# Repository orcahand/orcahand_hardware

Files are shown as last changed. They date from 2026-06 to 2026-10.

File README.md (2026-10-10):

<p align="center">
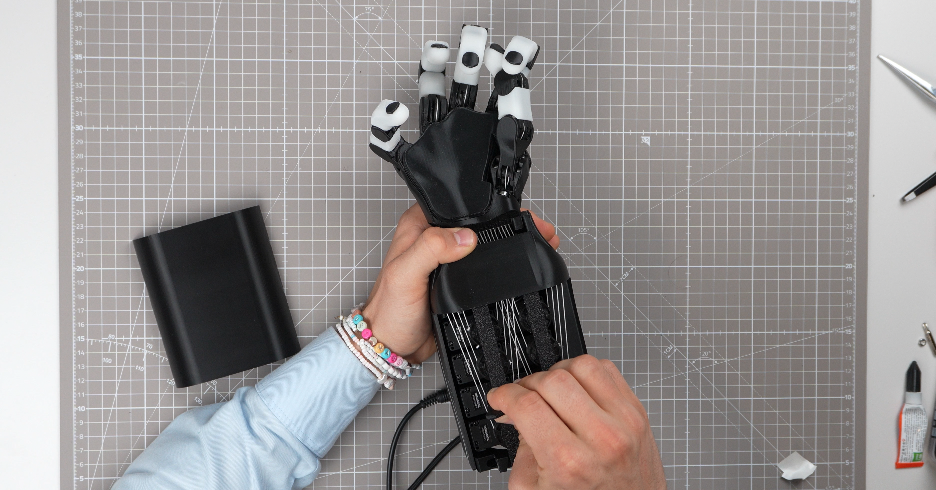
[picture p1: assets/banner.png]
ORCA Hand
  
</p>

<div align="center" style="line-height: 1;">
  
  
  
  
  <br>
  
</div>

# ORCA Hand Files

CAD and print files for the ORCA robotic hand.

## Print Files

There are two hand variants. Each ships one print file for the hand itself and one for the silicone skin molds:

| Variant | Hand print file | Silicone mold file |
|---|---|---|
| **Base hand** | `orca_v2/base/Prints-1100.3mf` | `orca_v2/base/SiliconeMolds-1100.3mf` |
| **Touch hand** (touch sensors in the fingertips) | `orca_v2/touch/Prints-2100.3mf` | `orca_v2/touch/SiliconeMolds-2100.3mf` |

All files are Bambu Lab Studio projects with pre-arranged plates and print settings.

### Hand print files (`Prints-*.3mf`)

Everything you need to print the hand. The ORCA Hand supports both **Feetech** and **Dynamixel** servos: print plate 1 (`DYNAMIXEL`) *or* plate 2 (`FEETECH`) for the tower, depending on your actuators. Every other plate is the same for both.

The print files also include the **skin parts as direct TPU prints** — the finger skins and the carpal skin — on their own `(TPU)` plates. They are white in the base hand and black in the touch hand. Printing the skins in TPU is the quickest way to get a complete hand.

### Silicone mold files (`SiliconeMolds-*.3mf`)

Print these molds, then cast the skins in silicone. **We recommend silicone skins** — they grip better and last longer than TPU. If you want something quick and dirty, the TPU-printed skins from the hand print file work as well.

The mold files contain the finger skin molds with their clips, the carpal molds, and the funnels for pouring. One plate (`WITH TPU (~85A)`) prints the flexible carpal mold halves in soft TPU; everything else is PLA.

> **Note:** It is still unverified whether the TPU-printed carpal skin fits into the carpals as tightly as the silicone one. If it is loose, glue it in.

If you prefer compression molding over pouring, `orca_v2/base/07_Molds/Compression-Molds.3mf` contains the compression molds for the finger and carpal skins.

## Repository Structure

```
orca_v2/                          # Current ORCA hand — shared base + variants
  base/                           # Base hand
    Prints-1100.3mf               # Hand print file (Dynamixel + Feetech plates)
    SiliconeMolds-1100.3mf        # Silicone skin molds
    01_Fingers/*.stl              # STL sources
    02_Carpals/*.stl              #   (incl. *_Skin_TPU.stl carpal skins)
    03_Wrist/*.stl
    04_ForeArm/*.stl
    05_Spools/*.stl
    06_CNC/                       # CNC parts (STEP + drawings)
    07_Molds/*.stl                # Mold STLs
    07_Molds/Compression-Molds.3mf  # Compression molds (alternative to pouring)
    09_Skin/*.stl                 # Finger skin STLs (TPU)
    <section>/step_files/*.step   # STEP sources, named like the STL they belong to
    ASSEMBLY_ADDENDUM.md          # Assembly notes
  touch/                          # Touch-sensor variant
    Prints-2100.3mf               # Hand print file (Dynamixel + Feetech plates)
    SiliconeMolds-2100.3mf        # Silicone skin molds
    01_Fingers/*-Touch.stl        # Override STLs; everything else comes from base/
    02_Carpals/*-Touch.stl
  lite/                           # Lite variant — STL + STEP sources only
  joint-sensing/                  # Joint-sensing variant
    PrintsJointSensing.3mf

orca_v1/                          # V1 design (self-contained, legacy)
  Print_Files_Bambu/*.3mf
  ORCA_Fingers/*.stl
  ...
```

Variant 3MFs under `orca_v2/<variant>/` resolve part names against their own variant folder first, then `orca_v2/base/`, so they pick up shared STLs from base without duplication (a variant's own copy of a name wins over base). Edit a base STL once and every variant 3MF that references it gets updated.

## Updating Print Files After STL Changes

```bash
# Find which 3MF(s) contain a given STL (cascades across variants)
python3 scripts/find_3mf_for_file.py orca_v2/base/05_Spools/BaseSpool.stl

# Update all parts in a 3MF from source STLs (variants pull base parts too)
python3 scripts/update_3mf.py orca_v2/touch/Prints-2100.3mf --all

# Preview without writing
python3 scripts/update_3mf.py orca_v2/base/Prints-1100.3mf --all --dry-run

# List parts inside a 3MF
python3 scripts/update_3mf.py orca_v2/base/Prints-1100.3mf --list

# End-to-end: find changed STLs, update affected 3MFs, commit and push
python3 scripts/update-print-files.py --git
```

## License

Copyright (c) 2026 ORCA Dexterity, Inc.

All files in this repository — hardware designs (CAD/STL/3MF) and source code —
are licensed under the [Creative Commons Attribution 4.0 International License
(CC BY 4.0)](LICENSE). You may share and adapt the material for any purpose,
including commercially, with appropriate credit. No patent or trademark rights
are granted.

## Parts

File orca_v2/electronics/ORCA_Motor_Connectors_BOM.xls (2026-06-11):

Comment | Designator | Footprint | JLCPCB Part #
PM254V-11-03-H85 | H1,H2 | HDR-TH_3P-P2.54-V-F | C541850

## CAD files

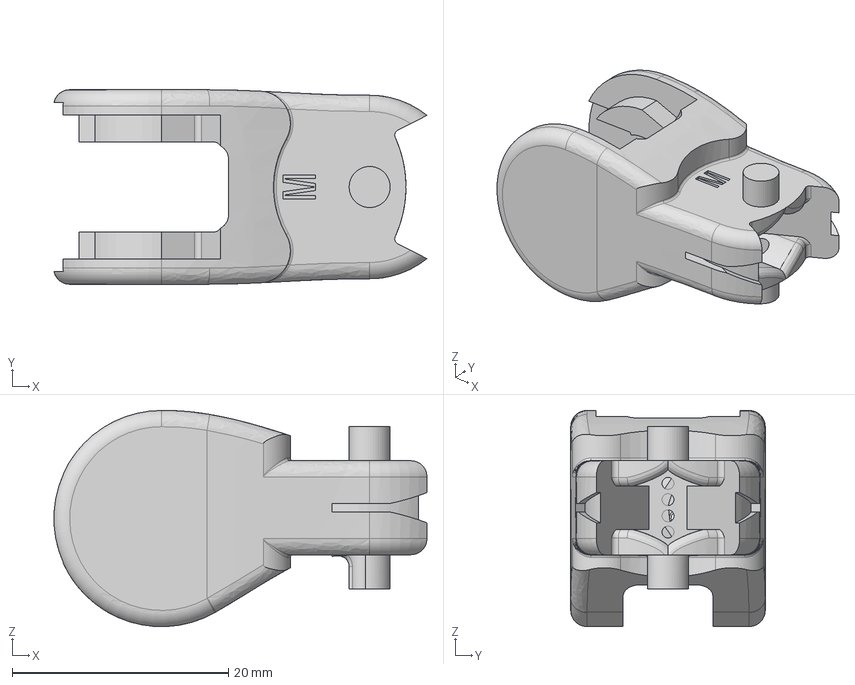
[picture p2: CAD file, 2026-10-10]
orca_v2/base/01_Fingers/step_files/M-AP.step
34.5 x 18.0 x 20.0 mm

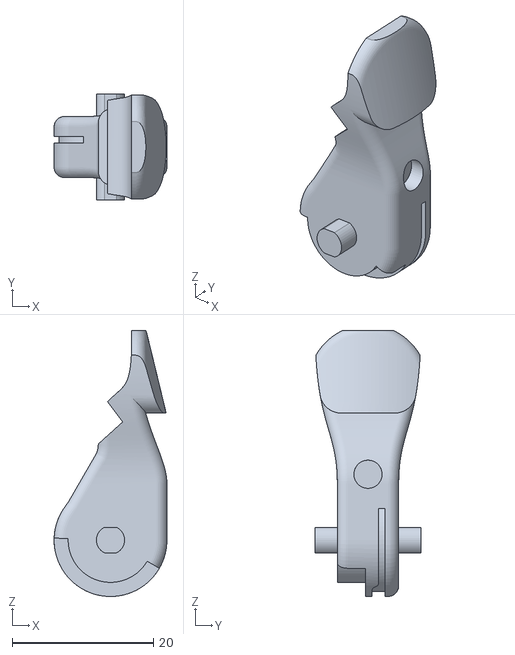
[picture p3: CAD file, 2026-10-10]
orca_v2/base/01_Fingers/T-DP.stl
16.0 x 15.0 x 37.7

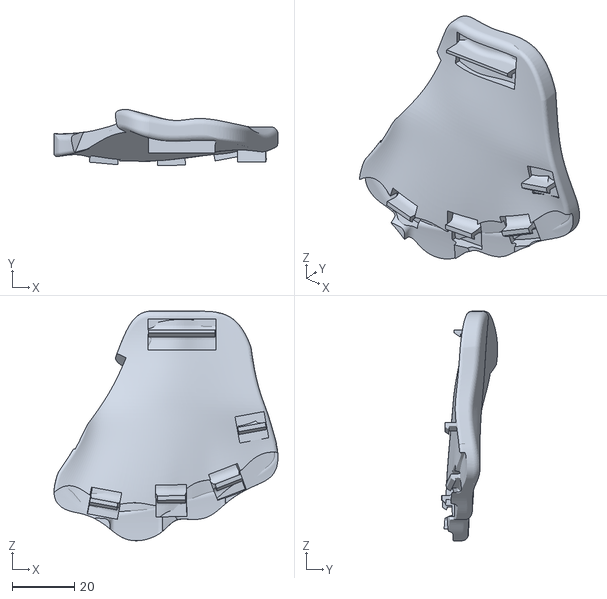
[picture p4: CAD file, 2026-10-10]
orca_v2/base/02_Carpals/L-Carpals_Skin_TPU.stl
72.2 x 18.2 x 74.0

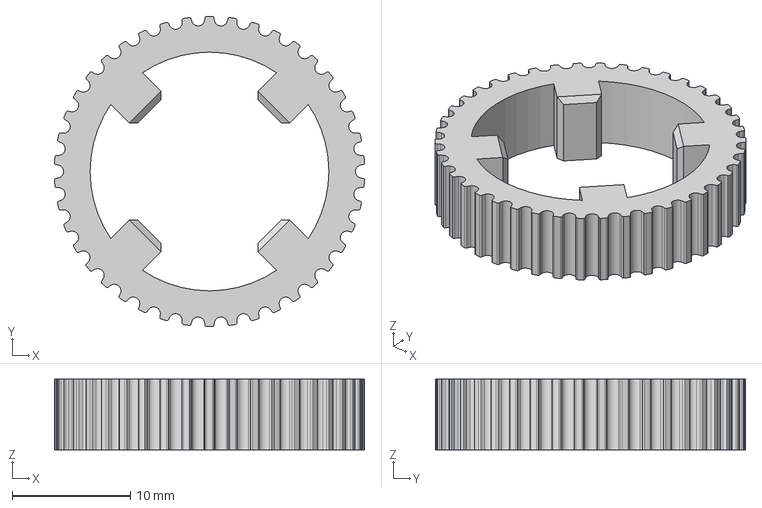
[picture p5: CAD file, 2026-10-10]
orca_v2/base/02_Carpals/step_files/CarpalsTeeth.step
26.2 x 26.3 x 6.00 mm

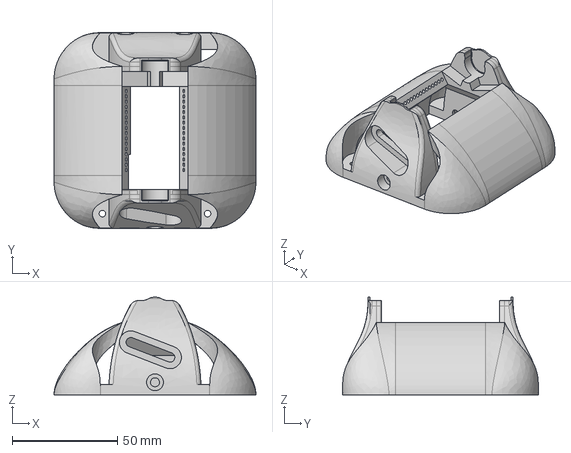
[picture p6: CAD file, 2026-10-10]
orca_v2/base/03_Wrist/step_files/WristStructure_Dynamixel.step
96.0 x 93.0 x 46.5 mm

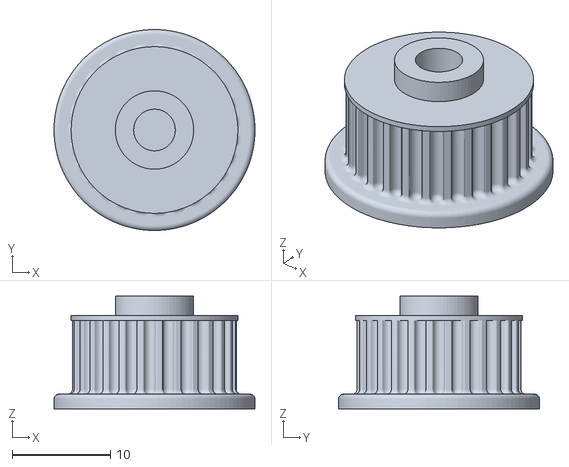
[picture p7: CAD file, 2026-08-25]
orca_v2/base/03_Wrist/WristTeeth.stl
20.5 x 20.5 x 11.5

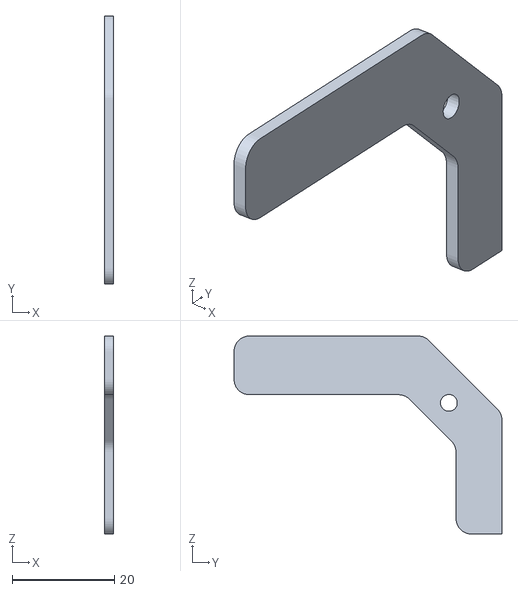
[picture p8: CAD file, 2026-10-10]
orca_v2/base/04_ForeArm/HullBack_CableCover.stl
1.85 x 52.5 x 38.8

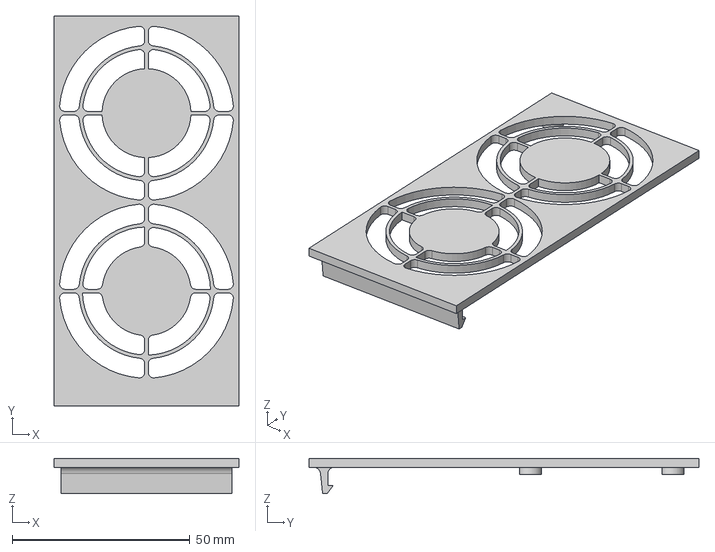
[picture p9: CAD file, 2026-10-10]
orca_v2/base/04_ForeArm/step_files/FanCover_TwoFans.step
52.0 x 109.6 x 9.90 mm

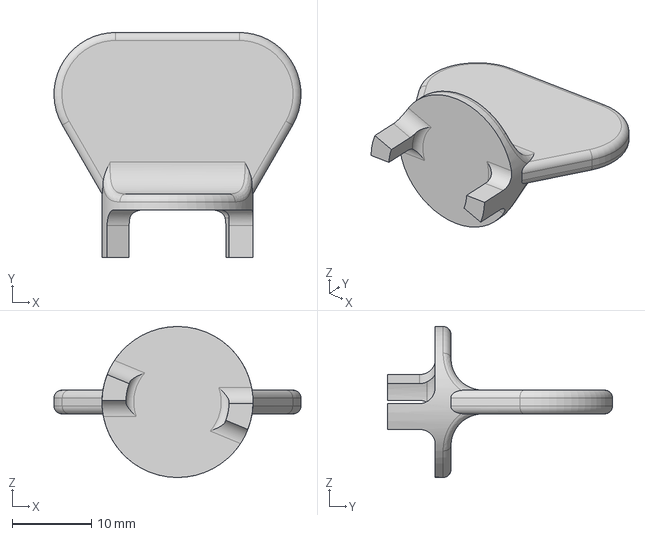
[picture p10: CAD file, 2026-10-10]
orca_v2/base/05_Spools/step_files/SpoolTensioner.step
31.1 x 28.3 x 19.0 mm

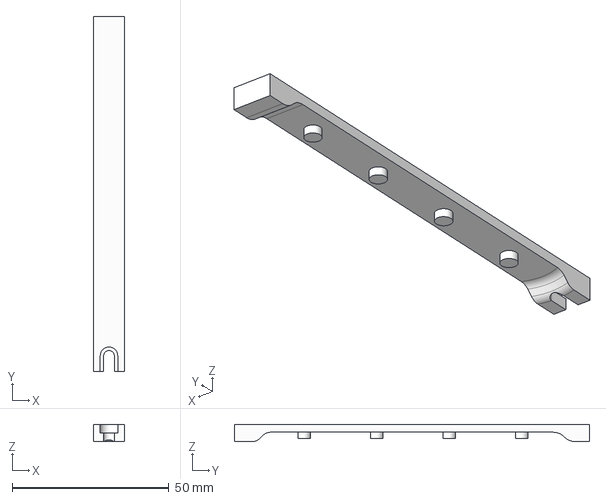
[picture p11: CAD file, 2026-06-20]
orca_v2/base/06_CNC/SpoolHolder_CNC.step
10.0 x 113.3 x 5.50 mm

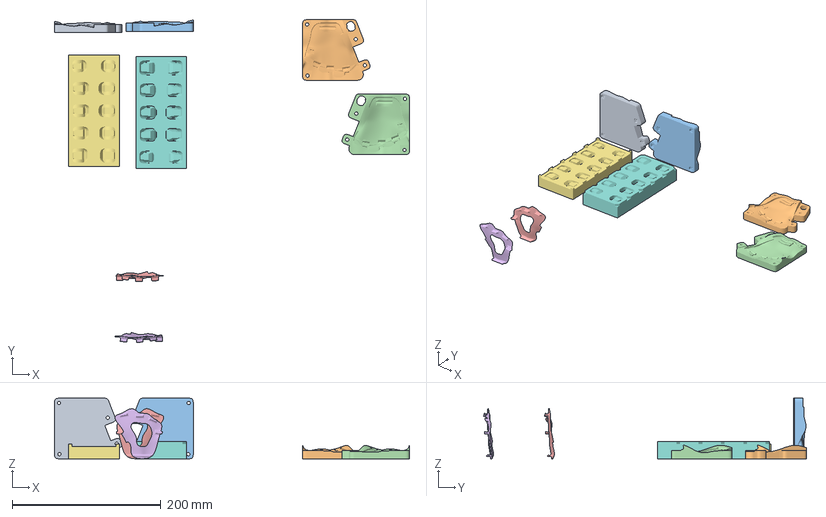
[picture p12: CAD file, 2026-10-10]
orca_v2/base/07_Molds/Compression-Molds.3mf
476.9 x 433.4 x 81.4 mm
L-CarpalsMold-A.stl
L-CarpalsMold-B.stl
R-CarpalsMold-A.stl
R-CarpalsMold-B.stl
CORE-L.stl
CORE-R.stl
PP_Skin_BottomMold.stl
PP_Skin_TopMold.stl

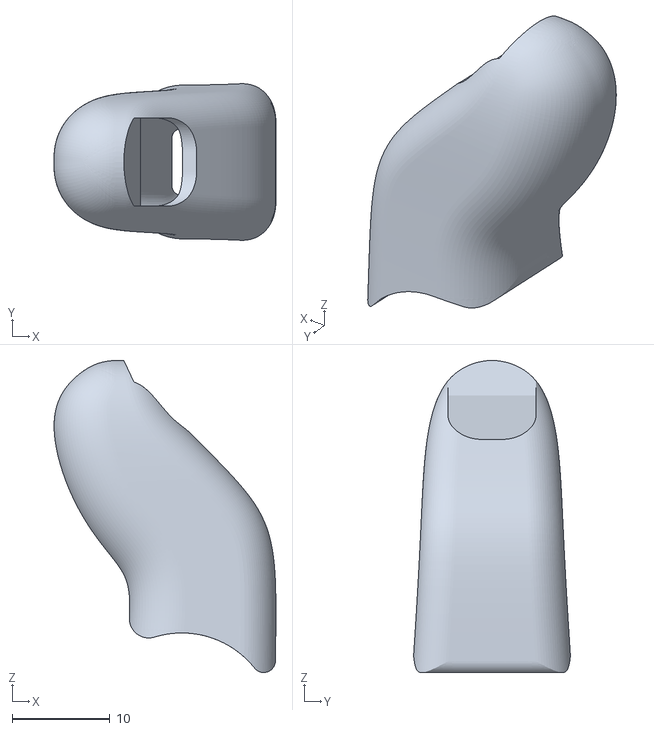
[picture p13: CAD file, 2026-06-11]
orca_v2/base/09_Skin/DP-Skin_P-DP-Skin_Skin.stl
22.7 x 16.0 x 31.9

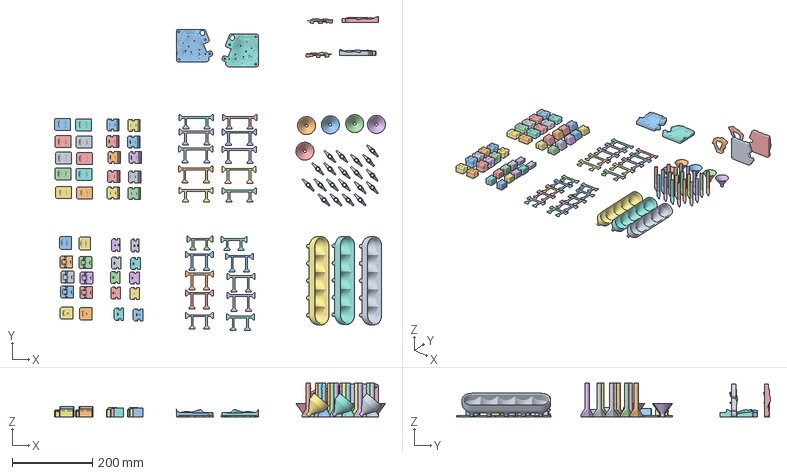
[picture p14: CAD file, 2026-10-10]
orca_v2/base/SiliconeMolds-1100.3mf
826.3 x 783.8 x 84.0 mm
L-CarpalsMold-A-Funnel.stl
Cylinder.stl x 20
L-CarpalsMold-B-Funnel.stl
R-CarpalsMold-A-Funnel.stl
R-CarpalsMold-B-Funnel.stl
CORE-L.stl
DP-SkinMold_M-DP-SkinMold_Clip.stl x 6
CORE-R.stl
DP-SkinMold_P-DP-SkinMold_Clip.stl x 2
PP-SkinMold_T-PP-Skinmold_BottomMold.stl x 2
PP-SkinMold_I-PP-SkinMold_BottomMold.stl x 2
PP-SkinMold_P-PP-SkinMold_BottomMold.stl x 2
M-DP-SkinMold_BottomMold.stl x 6
T-DP-BottomMold.stl x 2
PP-SkinMold_I-PP-SkinMold_TopMold.stl x 2
PP-SkinMold_P-PP-SkinMold_TopMold.stl x 2
DP-SkinMold_M-DP-SkinMold_TopMold.stl x 6
T-DP-Clip.stl x 2
T-DP-TopMold.stl x 2
P-DP-SkinMold_BottomMold.stl x 2
P-DP-SkinMold_TopMold.stl x 2
PP-SkinMold_M-PP-SkinMold_BottomMold.stl x 4
PP-SkinMold_M-PP-SkinMold_TopMold.stl x 4
PP-SkinMold_T-PP-Skinmold_TopMold.stl x 2
PP-SkinMold_I-PP-SkinMold_Clip.stl x 2
PP-SkinMold_P-PP-SkinMold_Clip.stl x 2
PP-SkinMold_T-PP-Skinmold_Clip.stl x 2
PP-SkinMold_M-PP-SkinMold_Clip.stl x 4
PentaFunnel.stl x 3
SingleFunnel.stl x 5

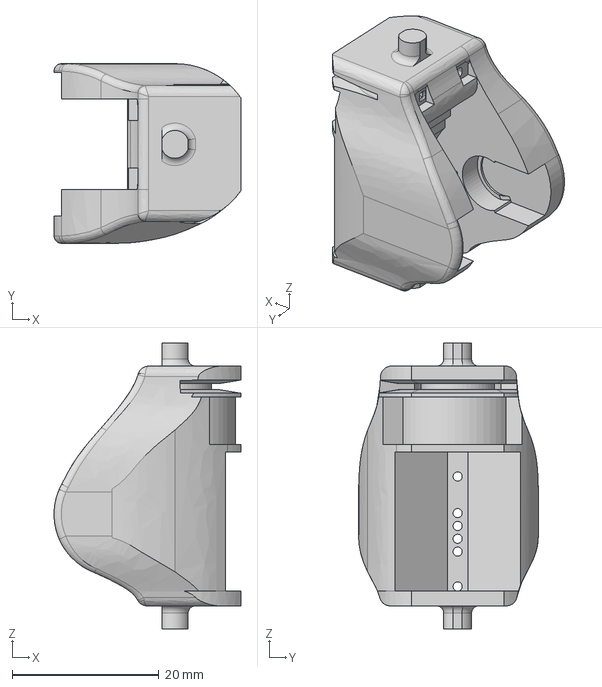
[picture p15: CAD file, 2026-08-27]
orca_v2/base/STEP Files/Hand/T-TP-R.step
25.5 x 24.5 x 39.0 mm

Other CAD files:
orca_v2/lite/BottomHolder.stl
orca_v2/touch/01_Fingers/M-AP-Touch.stl
orca_v2/touch/01_Fingers/step_files/L-T-AP-Touch.step
orca_v2/touch/02_Carpals/step_files/Carpals-R-Touch.step
orca_v1/ORCA_Fingers/DP.stl
orca_v1/ORCA_Fingers/L-AP.stl
orca_v1/ORCA_Fingers/L-I-PP.stl
orca_v1/ORCA_Fingers/L-IP.stl
orca_v1/ORCA_Fingers/L-M-PP.stl
orca_v1/ORCA_Fingers/L-P-PP.stl
orca_v1/ORCA_Fingers/L-T-AP.stl
orca_v1/ORCA_Fingers/L-T-DP.stl
orca_v1/ORCA_Fingers/R-AP.stl
orca_v1/ORCA_Fingers/R-I-PP.stl
orca_v1/ORCA_Fingers/R-IP.stl
orca_v1/ORCA_Fingers/R-M-PP.stl
orca_v1/ORCA_Fingers/R-P-PP.stl
orca_v1/ORCA_Fingers/R-T-AP.stl
orca_v1/ORCA_Fingers/R-T-DP.stl
orca_v1/ORCA_Fingers/T-TP.stl
orca_v1/ORCA_Misc/CameraMount.stl
orca_v1/ORCA_Molds/FingerTipMold-A.stl
orca_v1/ORCA_Molds/FingerTipMold-B.stl
orca_v1/ORCA_Molds/I-PP-SkinMold-A.stl
orca_v1/ORCA_Molds/I-PP-SkinMold-B.stl
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

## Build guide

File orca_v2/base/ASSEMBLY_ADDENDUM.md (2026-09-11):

# Addendum to the ORCA Hand V2 Assembly Tutorial

Due to the continuous development and improvement of the ORCA Hand, some new information is
currently missing from the [assembly tutorial video](https://www.youtube.com/watch?v=TgIz7HiyaoU).
This document lists these changes, as well as extra tips for easier assembly.

Timestamps below refer to that video.

**Important differences**

1. [PTFE tubes](#1-ptfe-tubes)
2. [Thumb AP pins](#2-thumb-ap-pins--timestamp-2104)
3. [Pins, gear and bearings for the carpals](#3-pins-gear-and-bearings-for-the-carpals--timestamp-3159)
4. [Spools](#4-spools--timestamp-5330)

**Tips**

5. [Inserting a PTFE tube which doesn't want to go in](#5-inserting-a-ptfe-tube-which-doesnt-want-to-go-in)
6. [Adding the PTFE tube over the M4 screws of the tower](#6-adding-the-ptfe-tube-over-the-m4-screws-of-the-tower--timestamp-3950)

---

## 1) PTFE tubes

PTFE tubes are added in some positions to reduce friction and wear.

### AP of each finger — timestamp 7:50

Each AP needs two PTFE tubes: one into each hole of the **wide** hole pair (highlighted in red).
Trim them so that they extend ~1 mm out on both sides (8–10 mm of PTFE tube is about the right length).

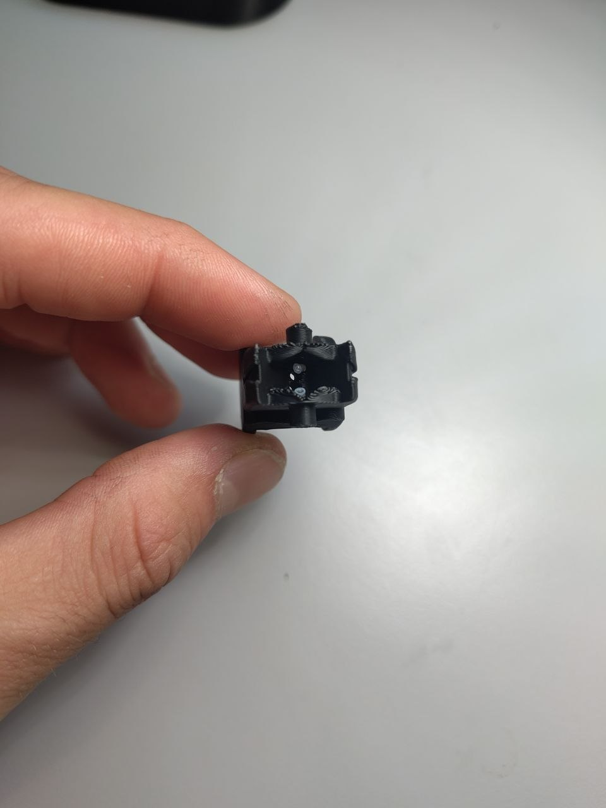
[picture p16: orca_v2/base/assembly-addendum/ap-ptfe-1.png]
The wide hole pair on the AP, highlighted in red

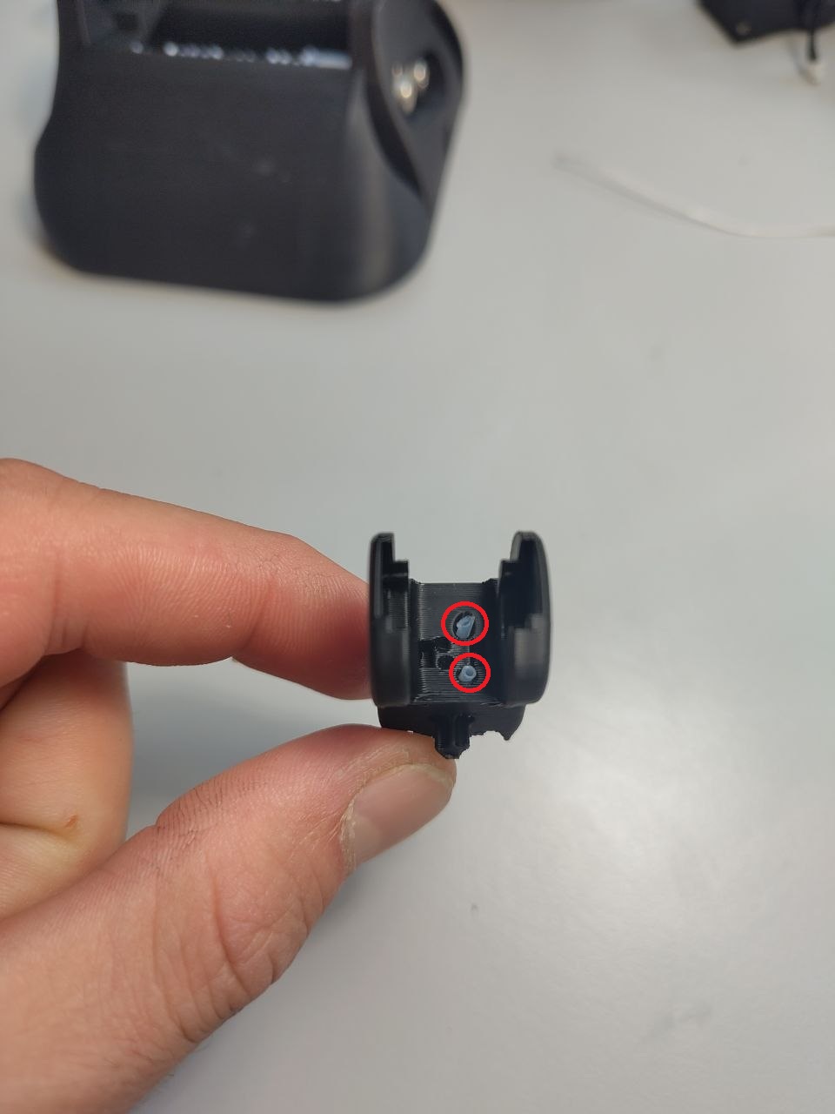
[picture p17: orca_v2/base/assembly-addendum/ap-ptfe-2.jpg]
PTFE tubes fitted in the AP, trimmed ~1 mm proud on each side


### Carpals — timestamp 25:05

Insert a PTFE tube into each of the 32 channels of the carpals. Trim so that they extend ~1 mm out
on both sides.

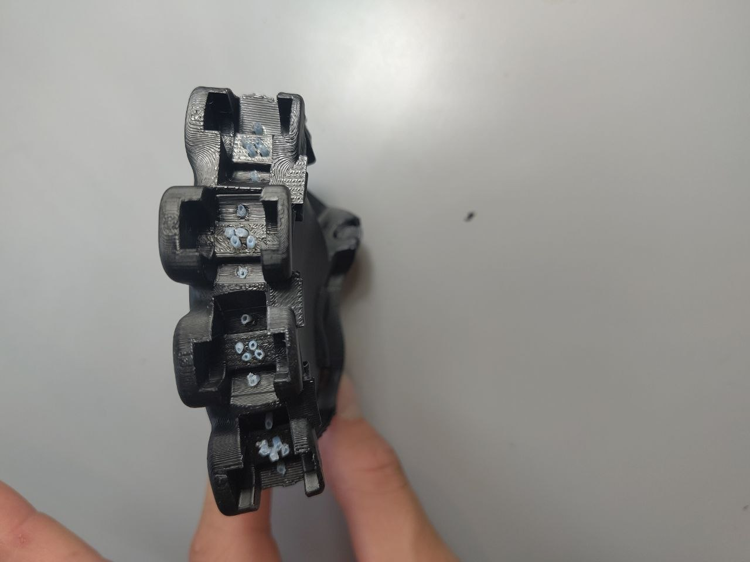
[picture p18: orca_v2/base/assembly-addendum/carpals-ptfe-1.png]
Carpals channels to be fitted with PTFE tube

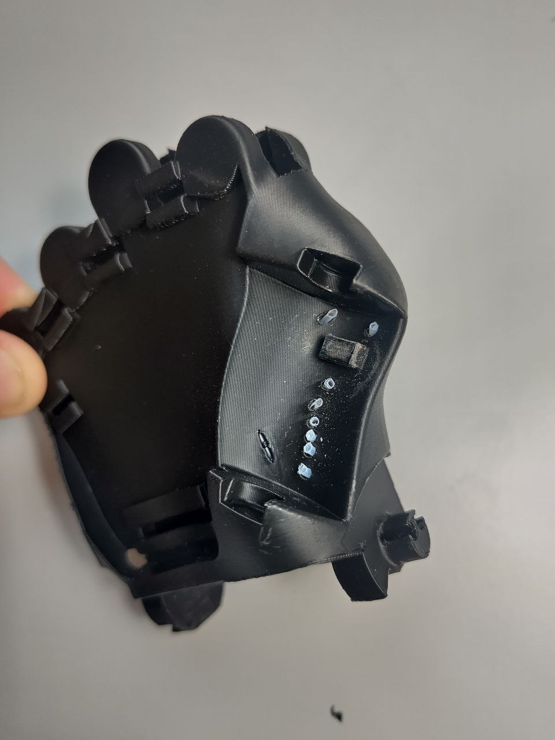
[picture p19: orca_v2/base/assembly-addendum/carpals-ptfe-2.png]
PTFE tubes being inserted into the carpals channels

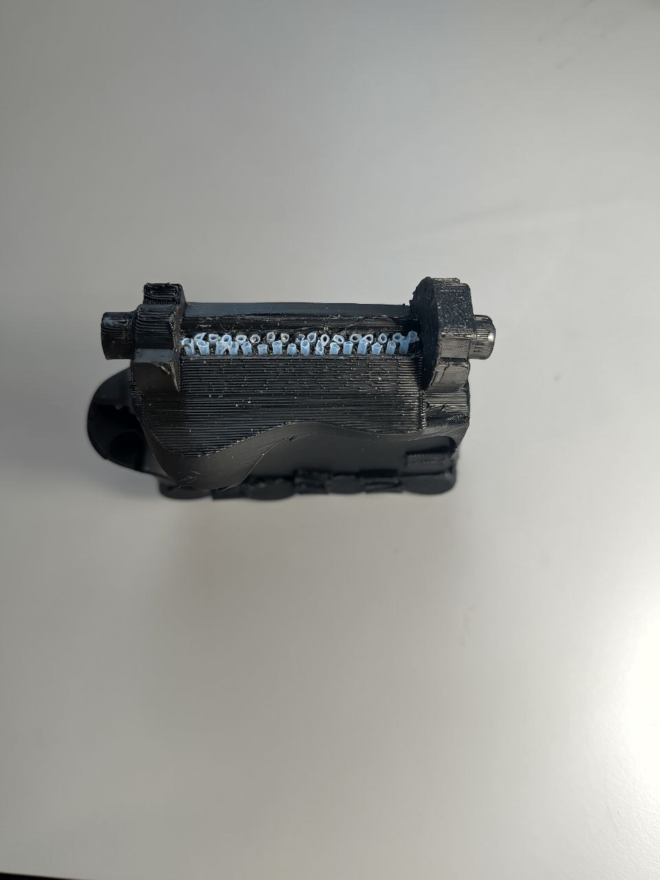
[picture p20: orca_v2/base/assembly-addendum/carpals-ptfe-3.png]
Carpals with all 32 PTFE tubes fitted and trimmed


### Tower — timestamp 40:50

Insert a PTFE tube in each of the 32 channels of the tower. Trim them so that they extend ~1 mm out
on both sides.

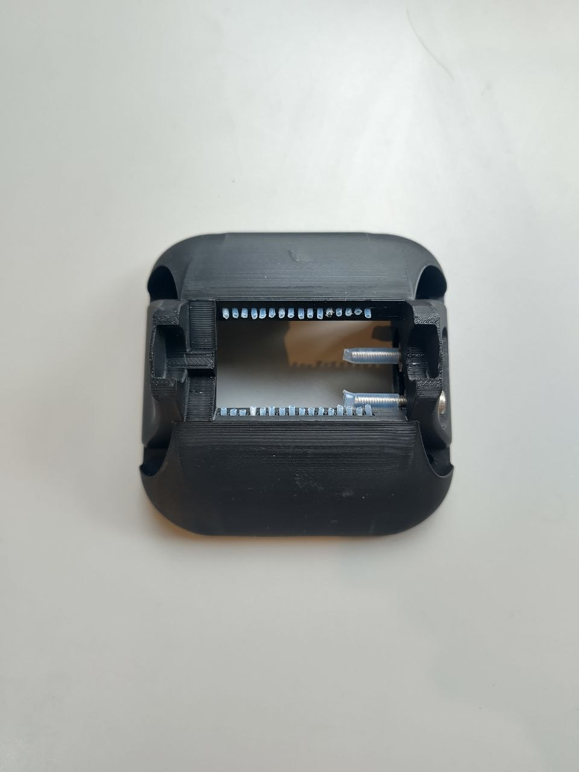
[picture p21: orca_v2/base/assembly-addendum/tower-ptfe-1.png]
Tower channels to be fitted with PTFE tube

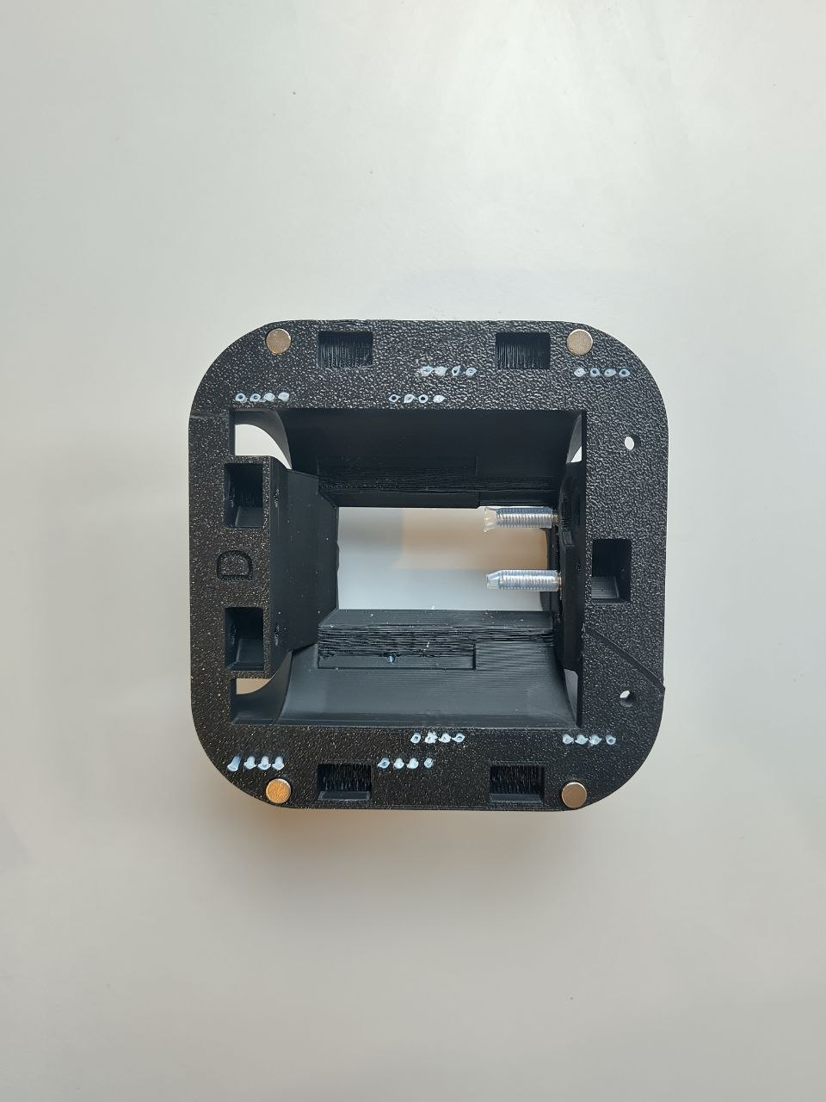
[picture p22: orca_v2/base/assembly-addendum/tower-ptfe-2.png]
Tower with PTFE tubes fitted and trimmed


## 2) Thumb AP pins — timestamp 21:04

The video shows an outdated part. The new version of the thumb AP doesn't have 6 individual holes
but one long slit. First route all tendons through the slit, maintaining the same order as presented
in the video to prevent tendons crossing. Then insert two 2×30 pins in their respective slots
(highlighted in red). Finally add the 4×8×3 bearings as shown in the video.

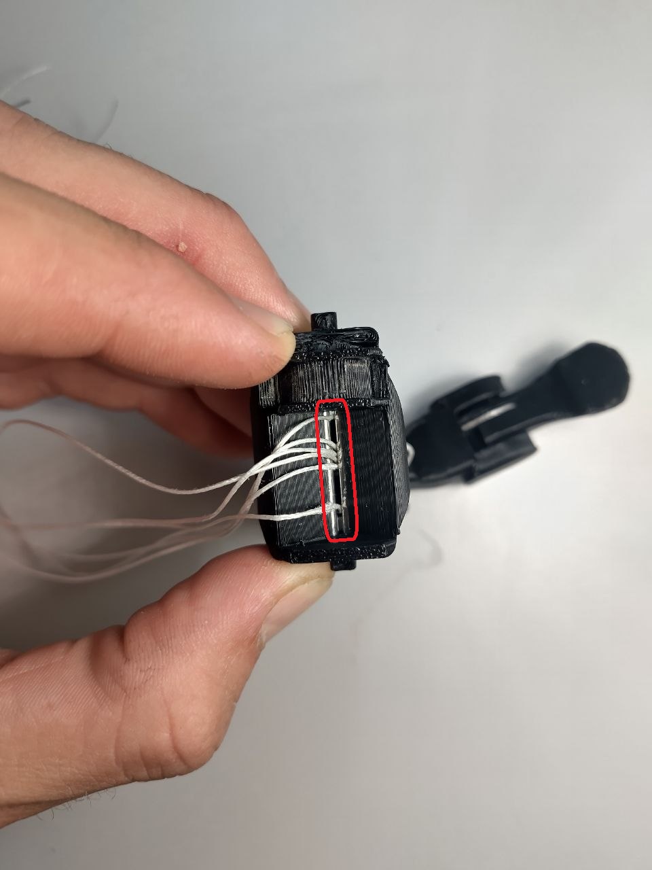
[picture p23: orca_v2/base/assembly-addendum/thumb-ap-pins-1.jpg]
New thumb AP with a single long slit in place of six holes

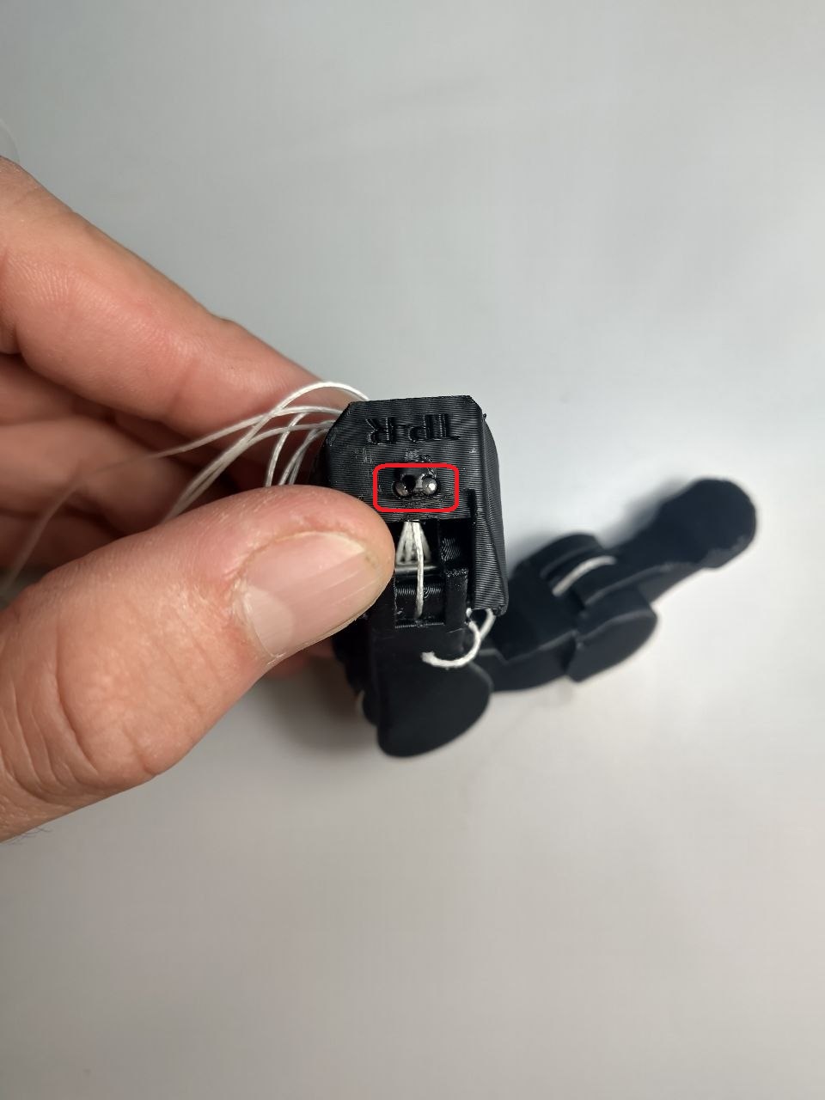
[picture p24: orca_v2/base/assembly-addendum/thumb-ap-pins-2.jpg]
The two 2x30 pin slots on the thumb AP, highlighted in red


## 3) Pins, gear and bearings for the carpals — timestamp 31:59

> This step is missing from the video.

After routing all tendons through the carpals and assembling all 5 fingers to the carpals, add two
3×50 pins at the wrist joint (3×45 also work, but barely).

Then mount the 3D printed gear for the carpals (highlighted in green), and mount two 8×13×4 bearings
(highlighted in red) on each end of the carpals' shaft.

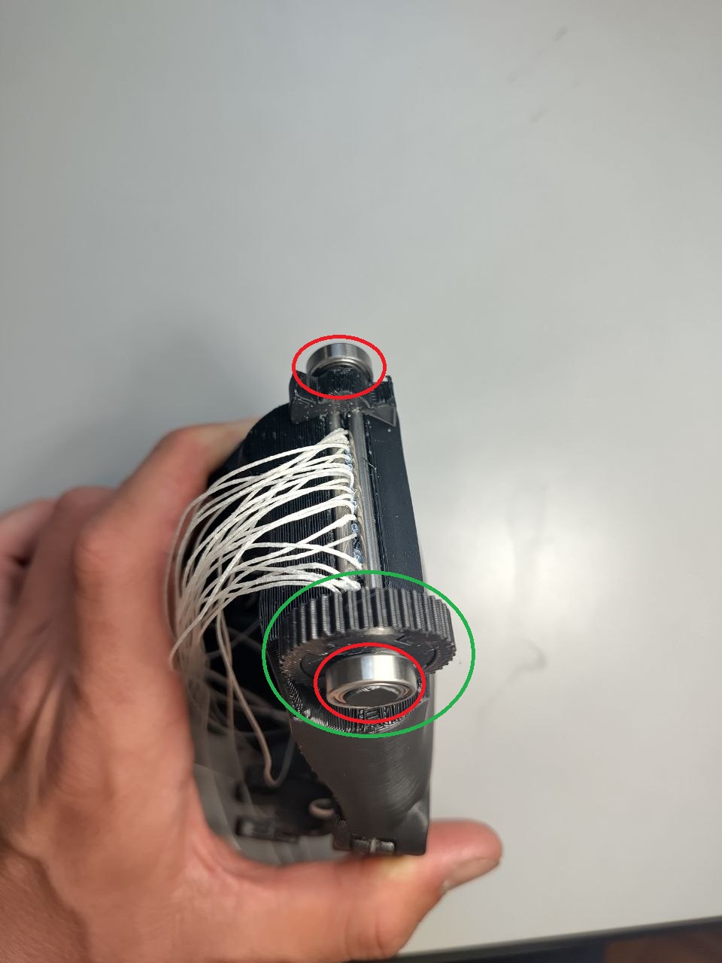
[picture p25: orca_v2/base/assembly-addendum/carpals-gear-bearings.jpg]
Carpals gear highlighted in green and the two 8x13x4 bearings highlighted in red


## 4) Spools — timestamp 53:30

The spools of the V1100 have slightly different dimensions from the V1000. You can easily tell them
apart: the V1100 spools have **4** holes for the screws instead of **5**.

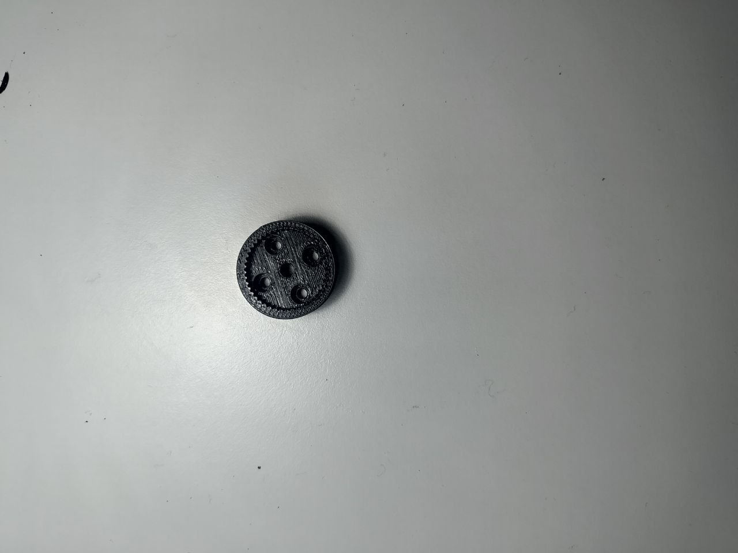
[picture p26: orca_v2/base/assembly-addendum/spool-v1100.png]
V1100 spool, with four screw holes

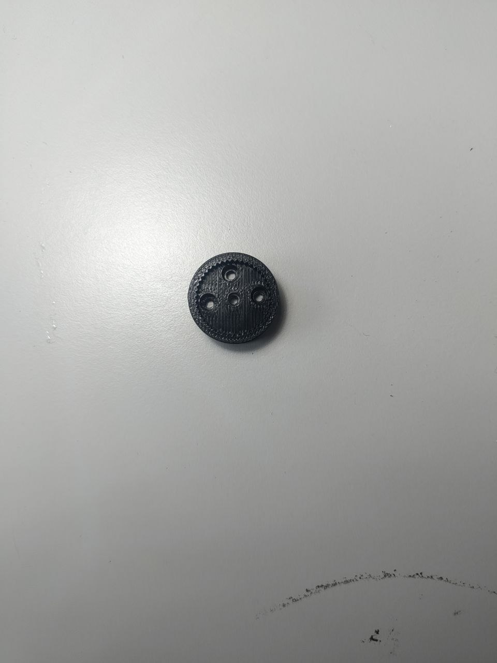
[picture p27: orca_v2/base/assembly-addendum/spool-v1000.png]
V1000 spool, with five screw holes


*Left: V1100 spool. Right: V1000 spool.*

---

## Tips

## 5) Inserting a PTFE tube which doesn't want to go in

It can be challenging to insert tubes into some particularly tight holes or long, winding channels.
One trick that helps is to prepare a tendon with a knot on one end and thread it through the PTFE
tube (step A). Then thread the tendon through the channel (step B) and use it to pull the PTFE tube
into the channel from the other end (step C), instead of trying to push it in.

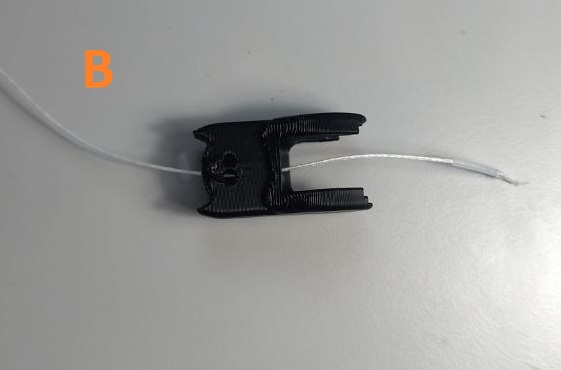
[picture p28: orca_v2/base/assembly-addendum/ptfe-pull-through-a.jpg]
Step A: knotted tendon threaded through the PTFE tube

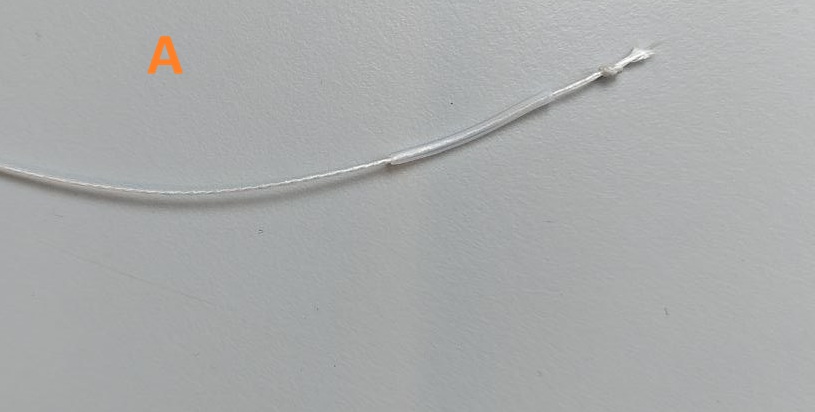
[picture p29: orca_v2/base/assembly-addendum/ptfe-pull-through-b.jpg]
Step B: tendon threaded through the channel

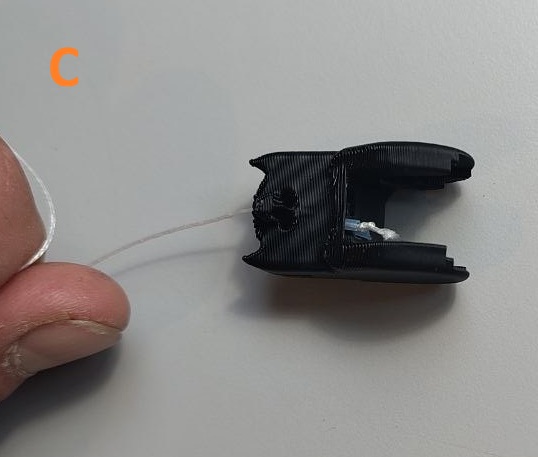
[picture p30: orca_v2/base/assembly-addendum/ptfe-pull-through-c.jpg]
Step C: pulling the PTFE tube into the channel by the tendon


## 6) Adding the PTFE tube over the M4 screws of the tower — timestamp 39:50

If the PTFE tube used to cover the M4 screws is difficult to squeeze on, hold the tube tightly
pressed on the screw with one hand and use a screwdriver to screw it into the PTFE tube.

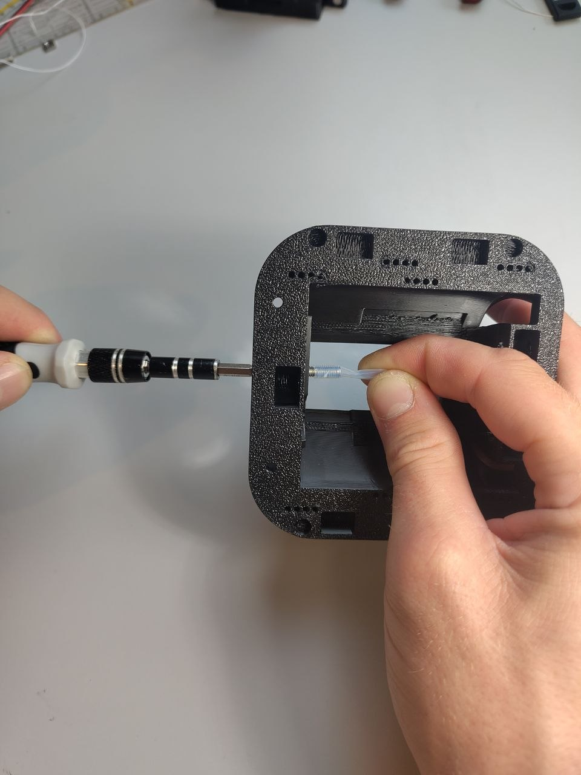
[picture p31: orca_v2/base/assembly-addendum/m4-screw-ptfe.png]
Using a screwdriver to drive an M4 screw into the PTFE tube


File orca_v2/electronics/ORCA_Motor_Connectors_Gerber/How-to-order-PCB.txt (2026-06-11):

How to Order PCB

Please refer to:
https://docs.easyeda.com/en/PCB/Order-PCB

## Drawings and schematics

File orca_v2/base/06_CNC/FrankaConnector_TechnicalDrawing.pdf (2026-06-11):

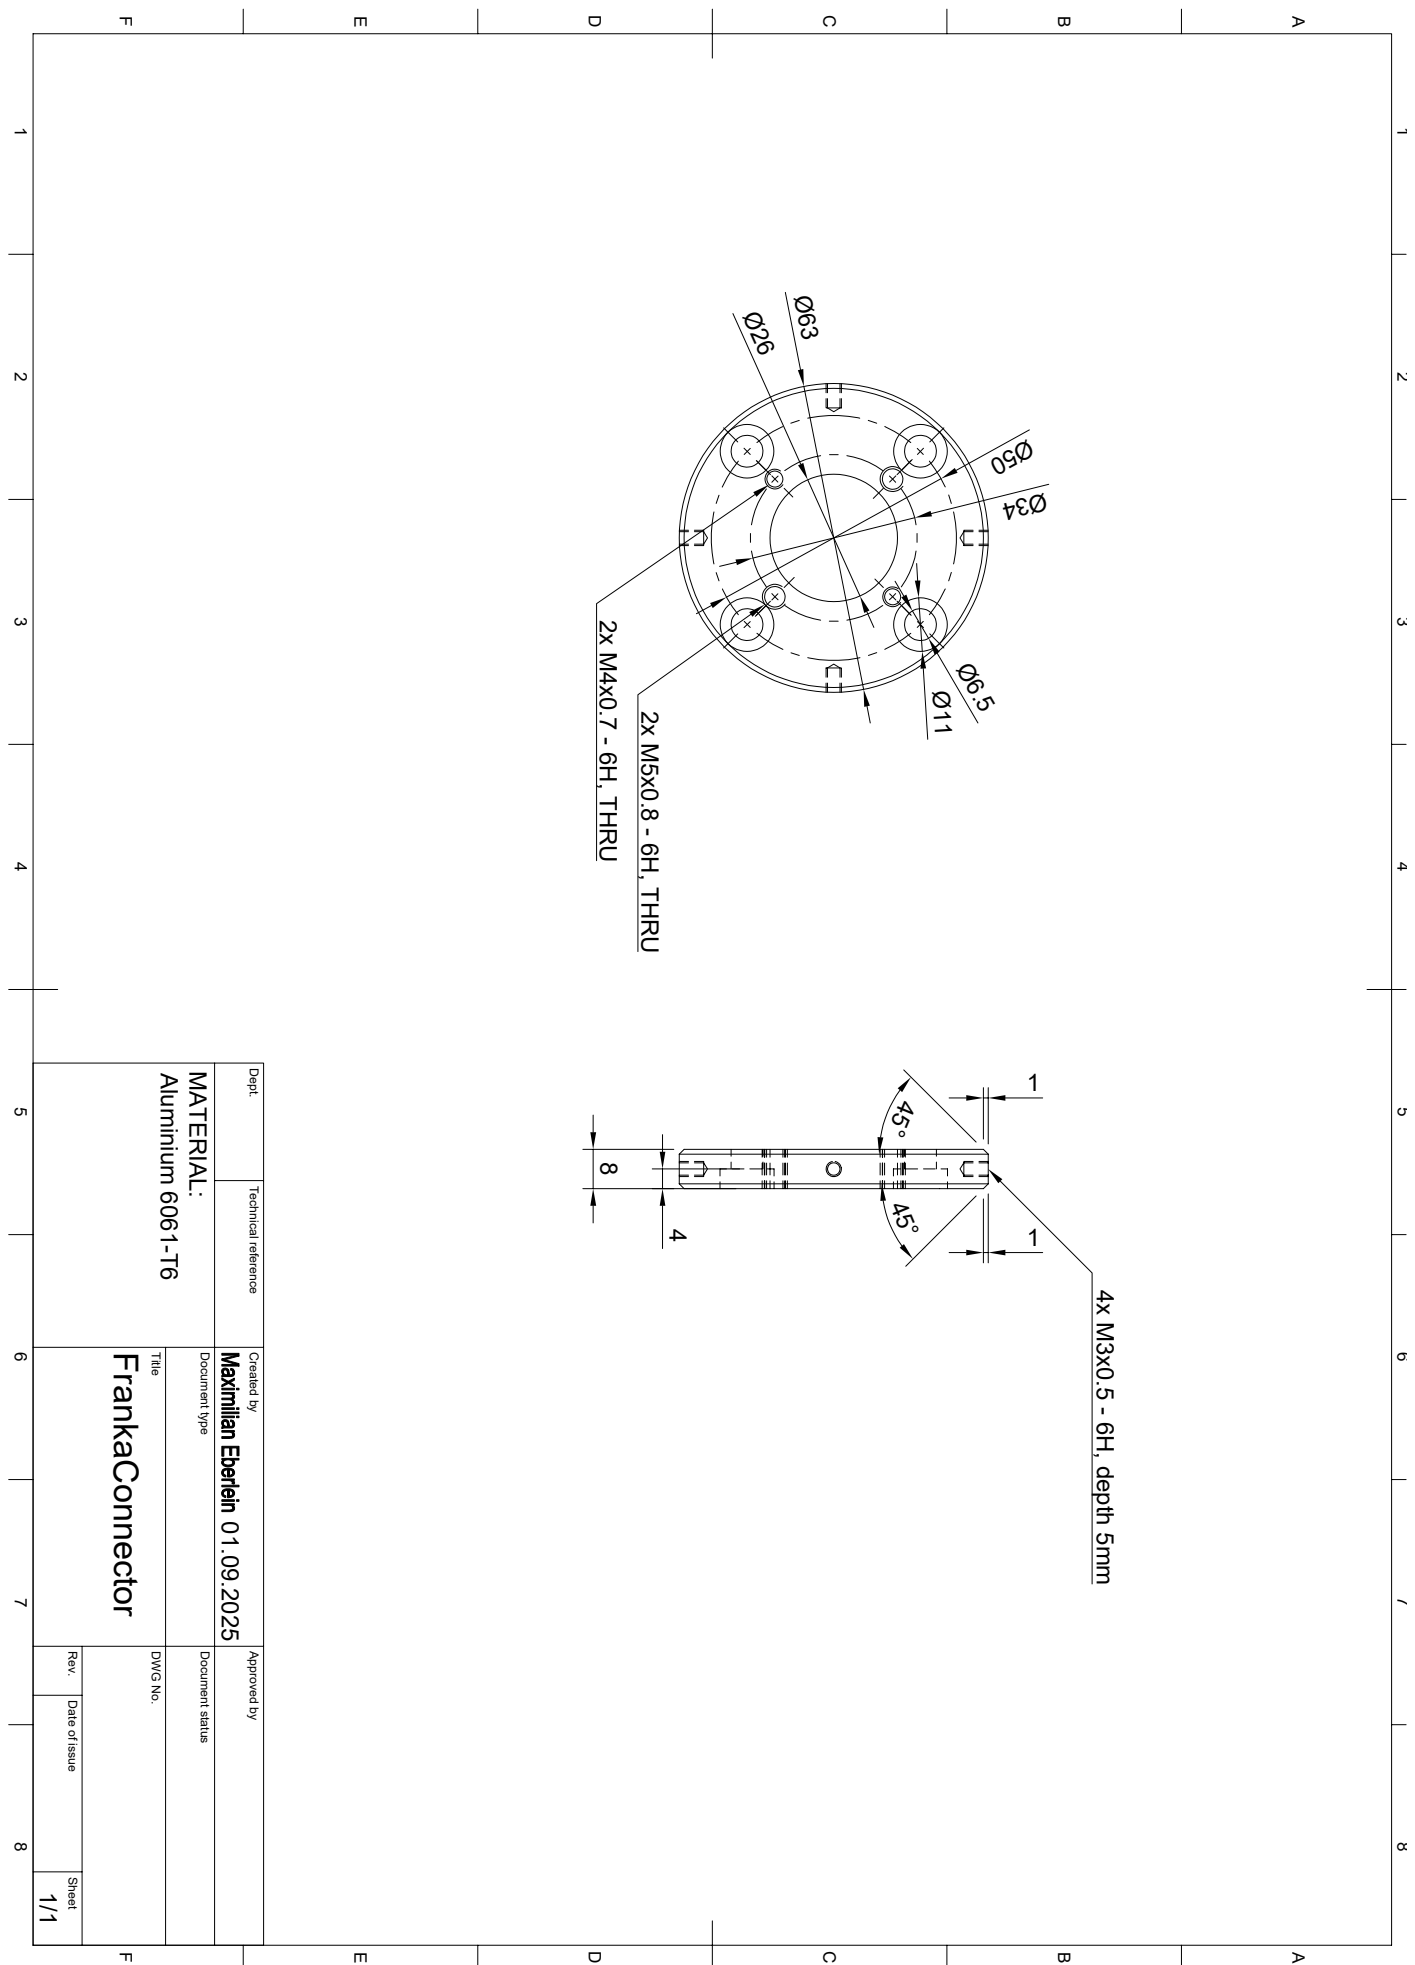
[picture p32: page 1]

1 A 2 3 4 5 6 7 8 1 2 3 4 5 6 7 8 FEDCB FEDCBA Dept. Technical reference Created by Approved by Title DWG No. Document type Document status Rev. Date of issue Sheet 01.09.2025 1/1 FrankaConnector 8 2x M4x0.7 - 6H, THRU 2x M5x0.8 - 6H, THRU 4x M3x0.5 - 6H, depth 5mm Ø11 Ø6.5 Ø63 Ø26 4 11 45° 45° Ø50 Ø34 Aluminium 6061-T6 MATERIAL:

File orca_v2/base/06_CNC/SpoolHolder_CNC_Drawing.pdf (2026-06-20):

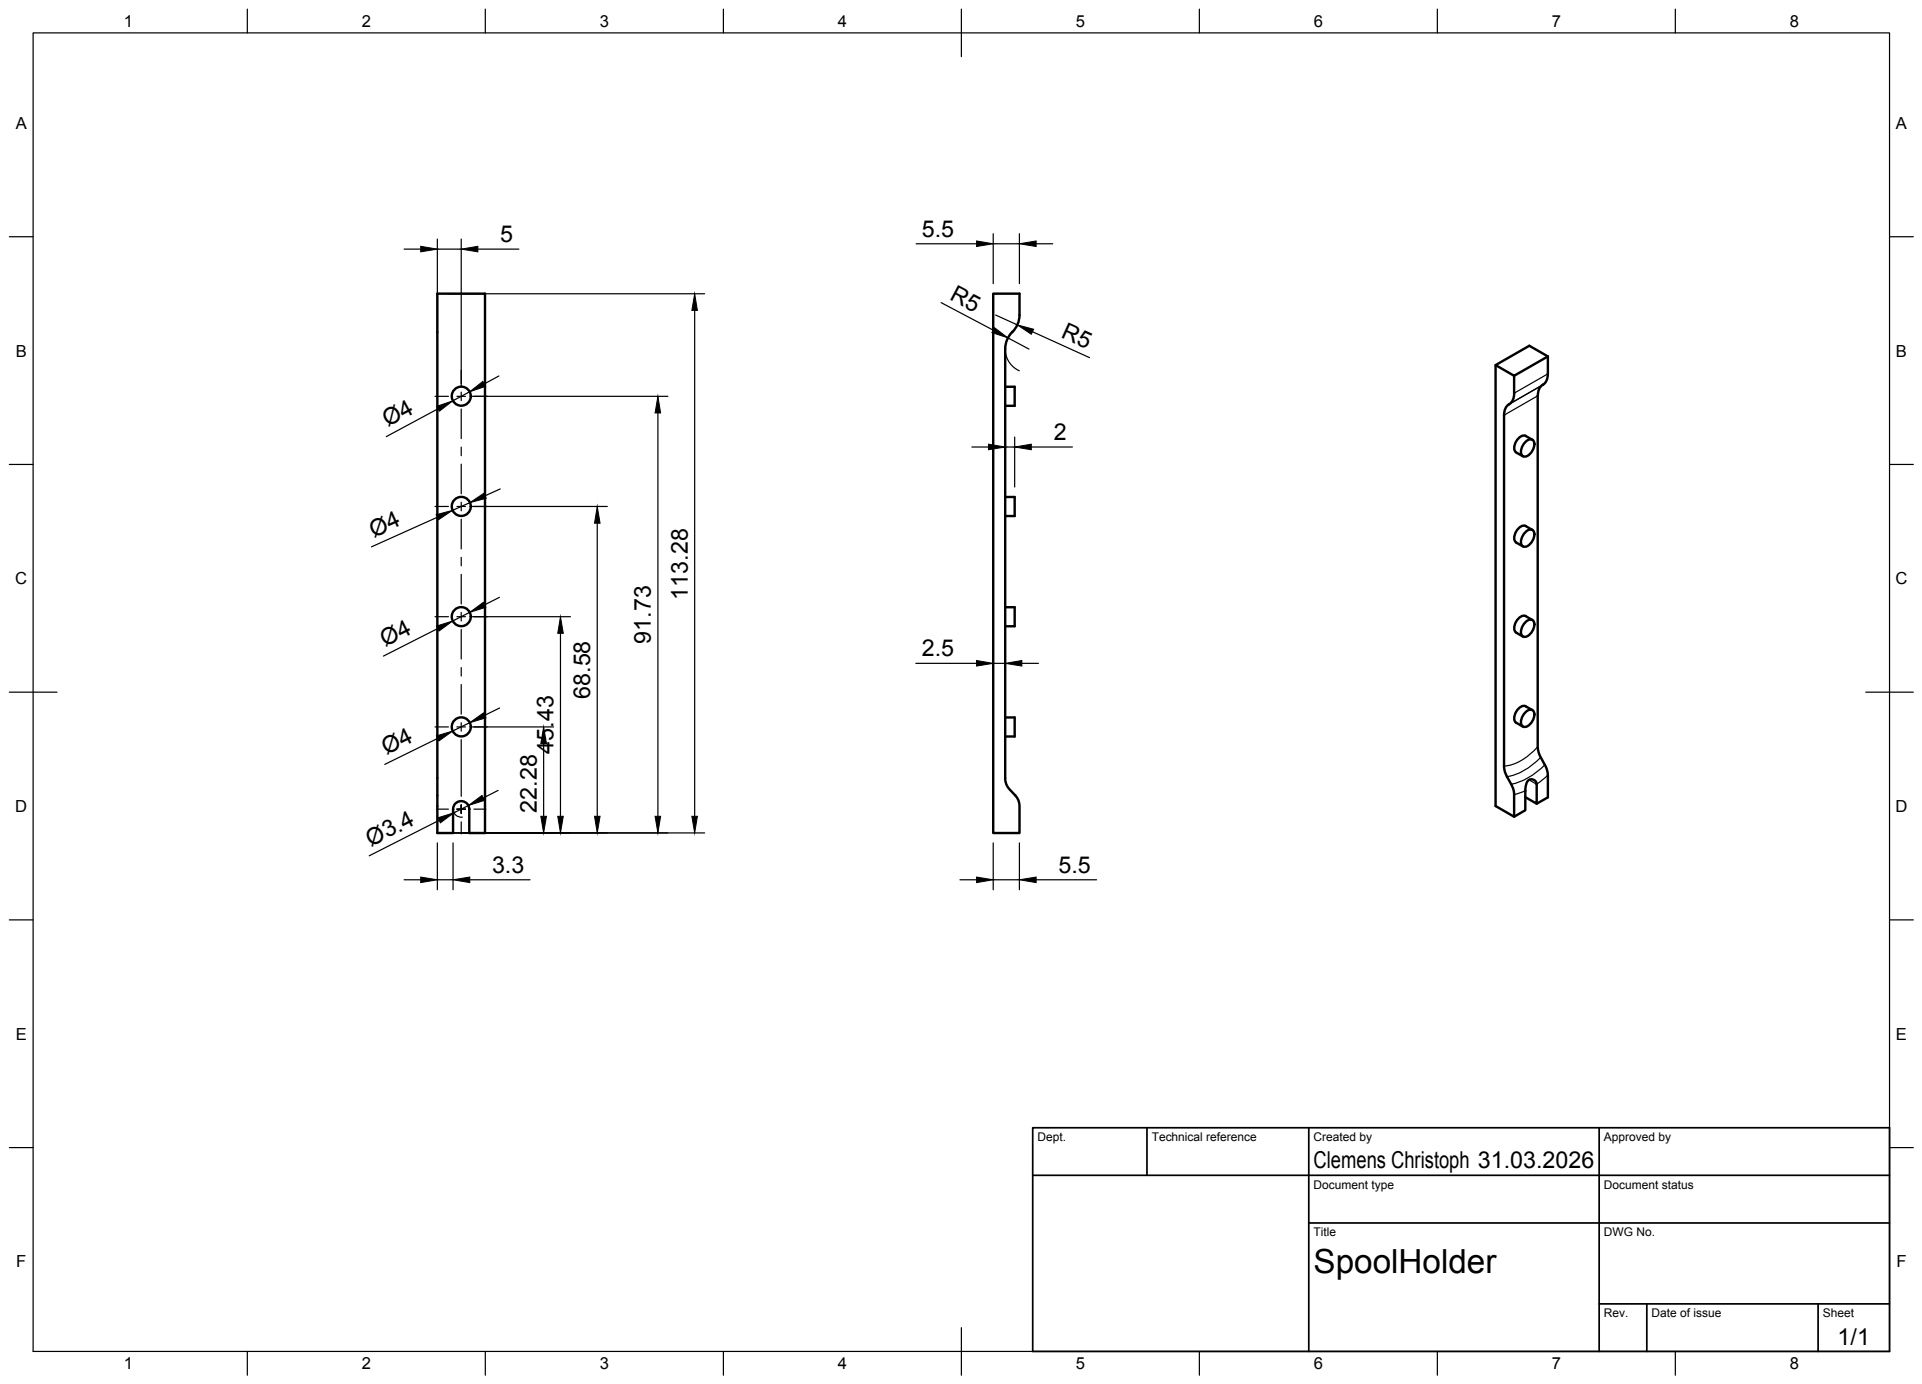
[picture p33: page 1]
8 BCDEF; ABCDEF; Title; DWG No.; Rev.; Date of issue; Sheet; Clemens Christoph 113.28

Dept. | Technical reference | Created by 31.03.2026 | Approved by

Document type | Document status

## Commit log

2026-06-11 Initial snapshot: ORCA hand hardware files (release-2026-06-06)
    [27TeethWristServo.stl, 42TeethCarpals.stl, ALLFINGERS.3mf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]
2026-06-20 Better tolerances for Nut in BottomTower
    [ForeArmStructure_Dynamixel.stl, ForeArmStructure_Dynamixel_TwoFans.stl, ForeArmStructure_Feetech_TwoFans.stl]
2026-08-14 Update AP parts to fix tendons slipping out
    Reworked the anterior phalanx (AP) geometry on all fingers and the thumb
    tip phalanges so the tendons stay seated in their channels. Regenerated the
    affected 1000/2000 print files for both base and touch variants.
    [Carpals-L-Touch.step, Carpals-R-Touch.step, Coav-L.step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]
2026-08-15 Fix ratchets showing the forearm mesh in the print plates
    Two ratchet instances per plate were mislabeled ForeArmStructure_Dynamixel.stl
    while their source_file and face count referenced Ratchet.stl. Both names
    shared one part id, so regenerating the plates wrote the forearm mesh into the
    object every ratchet instance shares, turning all 17 ratchets into forearm
    structures.
    Relabel the affected objects back to Ratchet.stl and reload the correct mesh.
    Claude-Session: https://claude.ai/code/session_01T8LHGjrL2qcr4J6fnhBpfa
    [Prints-1000-DX.3mf, Prints-1000-FT.3mf, Prints-2000-DX.3mf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]
2026-08-25 AP and TP fixed on all hand designs
    [L-T-AP.stl, LeftIndex.step, LeftIndex_AP.step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]
2026-08-25 Fixes for 1100
    [WristAdaper_Dynamixel.stl, WristAdaper_Feetech.stl, WristTeeth.stl]
2026-08-26 1100 print files
    [Clips-Only.3mf, HullBack.stl, I-AP-L.stl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]
2026-08-26 Prints 2100
    [I-AP-L-Touch.stl, I-AP-R-Touch.stl, L-T-AP-Touch.stl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]
2026-08-26 Restore Prints-1000 DX and FT print files
    Bring back orca_v2/base/Prints-1000-DX.3mf and Prints-1000-FT.3mf,
    which were removed in 3157740 when the 1100 print files were added.
    Claude-Session: https://claude.ai/code/session_01P1HFkeowEYxxffgNRTrAvX
    [Prints-1000-DX.3mf, Prints-1000-FT.3mf]
2026-08-26 Update 1.01 of Prints 1100 (only dx)
    [I-AP-L-Touch.stl, I-AP-L.stl, I-AP-R-Touch.stl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]
2026-08-27 Carpals with bigger bearings
    [L-Carpals.stl, R-Carpals.stl]
2026-08-27 TP Fix
    [Prints-1150-DX.3mf, T-TP-L.step, T-TP-L.stl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]
2026-08-27 another TP fix
    [Prints-1150-DX.3mf, T-TP-L.step, T-TP-L.stl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]
2026-08-29 Remove joint sensing STEP export folder
    Claude-Session: https://claude.ai/code/session_01MaH1QBpHLfZ5krrZ4NHomx
    [LeftIndex.step, LeftIndex_AP.step, LeftIndex_PP.step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]
2026-09-11 Update base hand to V1100
    Replace the V1000 print plates with a single consolidated Prints-1100.3mf
    containing plates for both Dynamixel and Feetech actuators, and sync the
    28 base STLs that changed between V1000 and V1100:
    - 01_Fingers: all 16 phalanges (AP/IP/PP, thumb TP/DP/T-AP)
    - 02_Carpals: L-Carpals, R-Carpals
    - 03_Wrist: wrist structures and adapters (DX + FT), WristTeeth
    - 04_ForeArm: HullBack
    - 05_Spools: BaseSpool, Ratchet, SpoolCover, SpoolTensioner
    The V1000 plates remain retrievable at the v1000 tag.
    README updated to match the new single-file layout for the base hand.
    Claude-Session: https://claude.ai/code/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
    [BaseSpool.stl, HullBack.stl, I-AP-L.stl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]
2026-09-11 Add V1100 assembly addendum
    Addendum to the ORCA Hand V2 assembly tutorial video, covering what has
    changed since it was recorded: PTFE tubes on the APs, carpals and tower;
    the redesigned thumb AP with a single slit instead of six holes; the
    carpals wrist pins, gear and bearings (a step missing from the video);
    and how to tell V1100 spools from V1000 ones. Plus two assembly tips.
    Sourced from the shared Changes V1000->V1100 document, with its 16
    figures committed alongside under assembly-addendum/.
    README gains an Assembly section linking to it.
    Claude-Session: https://claude.ai/code/session_01GJicpetXzMFUbESxXH3gnH
2026-09-16 improved the back hull plate, added a small piece to cover cables in the back hull
    [HullBack.stl, HullBack_CableCover.stl]
2026-09-16 Replace Prints-1100.3mf with corrected version
    Claude-Session: https://claude.ai/code/session_015NDNzKsaYY8aMzE3Y9u1hi
2026-09-18 Update SpoolCover in Prints-1100
    New SpoolCover.stl geometry, mesh replaced in Prints-1100.3mf on top of the wrist adapter fix.
    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
    [SpoolCover.stl]
2026-09-18 Updated the top spools in Prints-1100
    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
2026-10-10 Remove assembly manual from PR
2026-10-26 Rename CNC plate: FDM not recommended
